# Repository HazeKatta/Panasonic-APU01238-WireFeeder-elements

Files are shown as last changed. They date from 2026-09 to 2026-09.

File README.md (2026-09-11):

# Panasonic Wire Feed Unit: `WGIII/APU01238`
***Available on*** [Onshape](https://cad.onshape.com/documents/fc67ad3c9c1f68b02d99dc8a/w/f257942ea42ffc9f7acd28aa/e/a838ed4791a7bb28b46b23de)
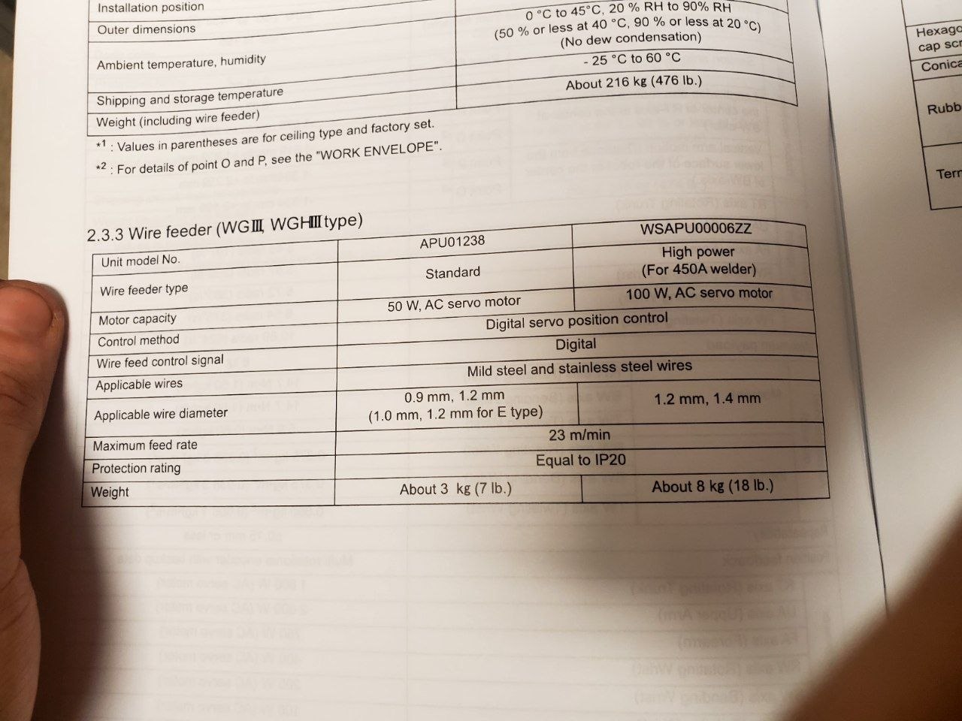
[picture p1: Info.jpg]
Real example


# What alternatives/spares does this repo provides

## Doors (2 variants):
Doors are not sold themselve you normally need to buy whole new `Wire Feeder` (or just not sold by Valk Welding B. V.)  
Price of those Doors was seen on EBay with 60$ price (used).
* Body: 2 variants
* Latch: 2 variants
* List of components like `seagers` and so on...
* Pin drawings  

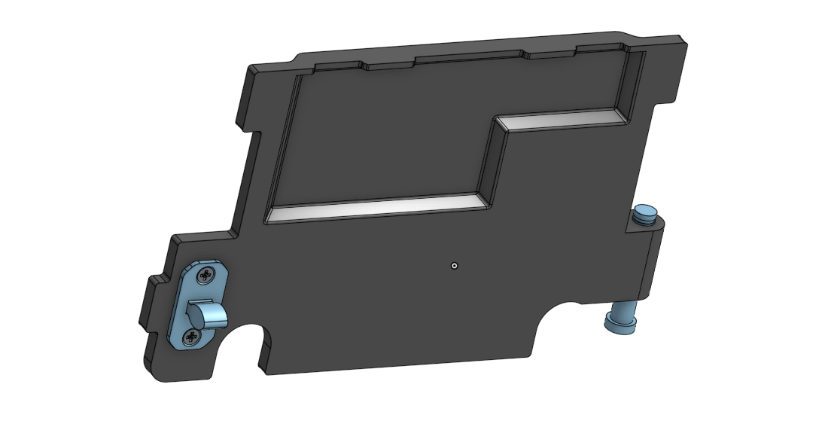
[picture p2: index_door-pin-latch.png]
Classic

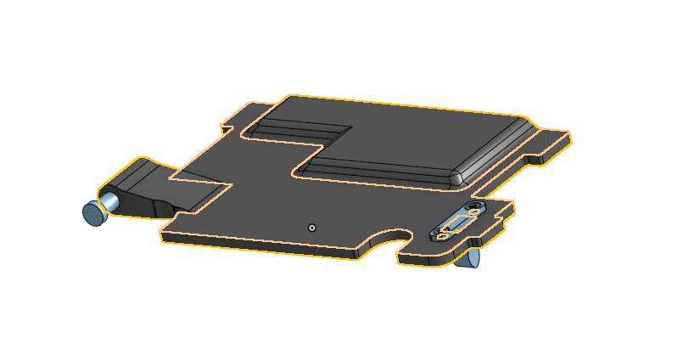
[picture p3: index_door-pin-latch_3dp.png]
More 3D printer friendly


## Mount:
* Metal bracket: classic & sheet metal alternative (2&4 mm sheets)  
* Insulator
* Metal L-profile seen below
* OFC: list of standard components

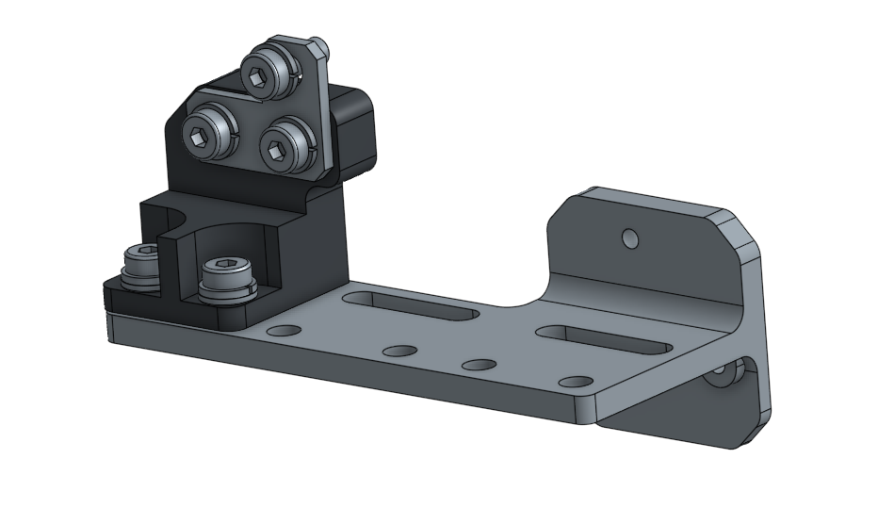
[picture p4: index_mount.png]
  

## Inside wire guide right between the rollers
* Brass block drawings
* Guide tube dimensions
* Used screws  

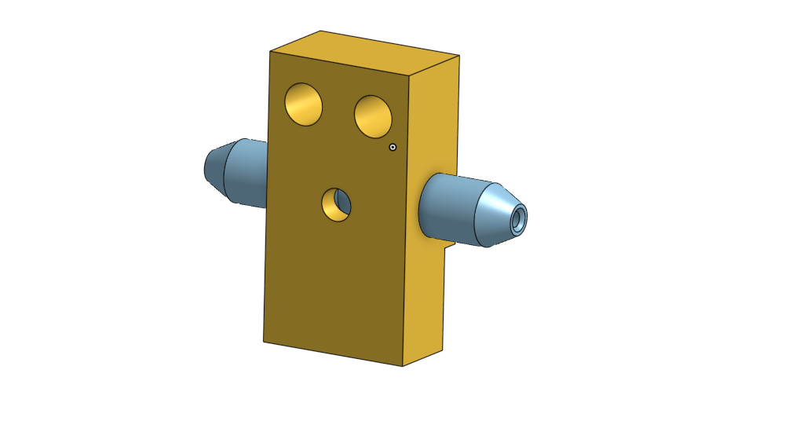
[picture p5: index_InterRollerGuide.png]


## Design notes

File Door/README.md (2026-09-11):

# Door
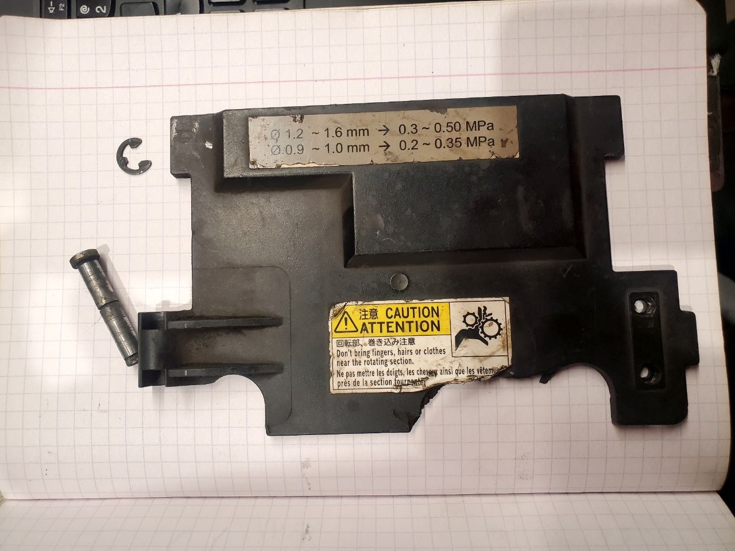
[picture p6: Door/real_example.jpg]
Real example

Consists of **one** element, but as you can see `it` also requires:
* [magic pin (click to go to it's section)](#door-pin) - can be made from soft material, even from plastic if needed
* magic Seager E-Clip:
  * outer diameter: 11mm
  * inner diameter: 5.20-5.50mm
  * thickness: 0.7mm (up 1.0mm)

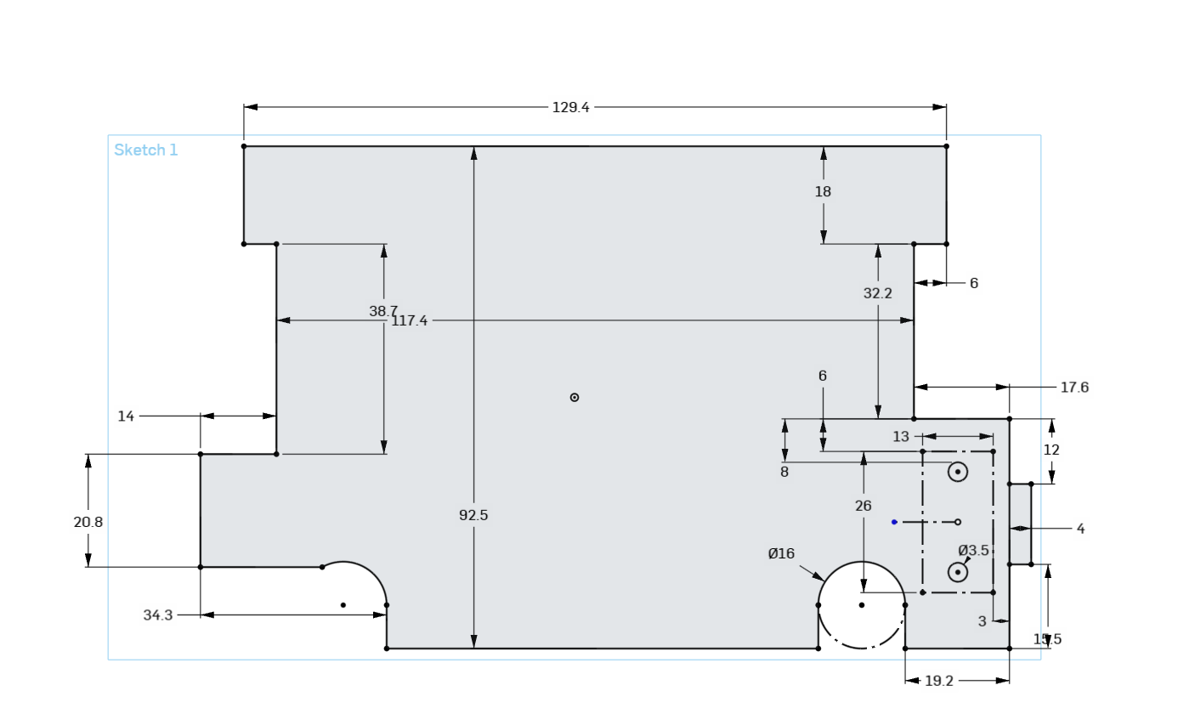
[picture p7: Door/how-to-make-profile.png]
how to recreate?

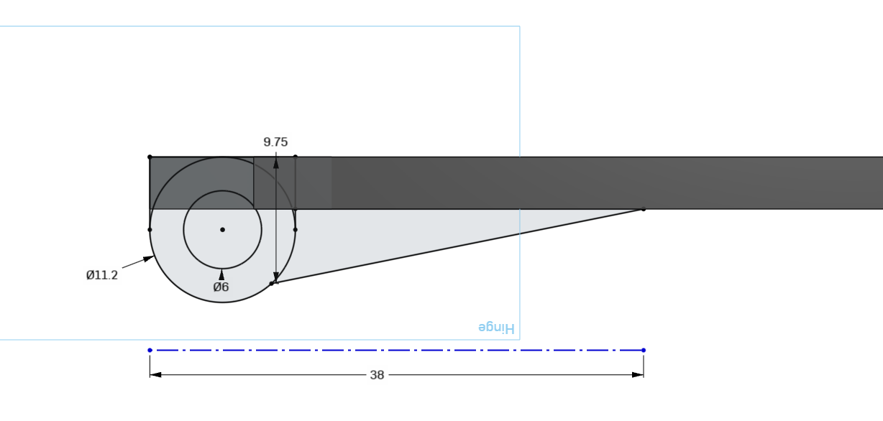
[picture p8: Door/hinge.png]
how to recreate hinge?

#### Plate is 3mm thick
### How does proposed alternative look like?
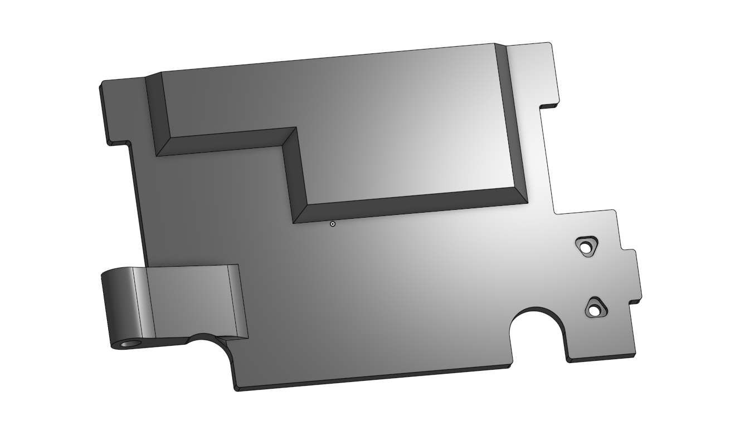
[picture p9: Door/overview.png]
3D printed alternative

As you can see cutouts for M2.5 nuts are triangular to cut accelerate/decelerate ops. for faster printing. Those nuts don't get fasten enough to maximize contact area.

#### 3D printing friendlier version
**Note that alternative versions are not cross-compatible!**
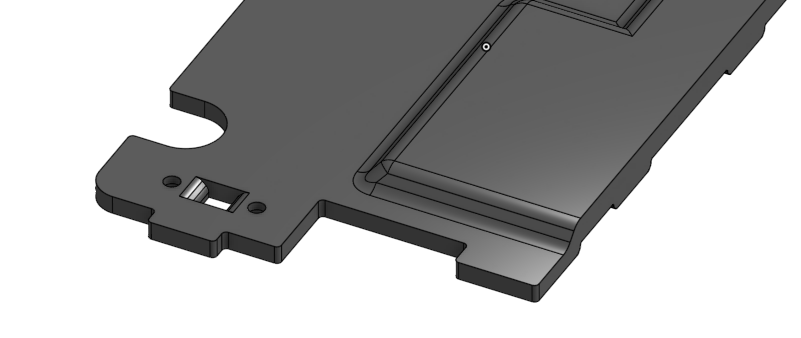
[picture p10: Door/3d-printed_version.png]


## Door pin
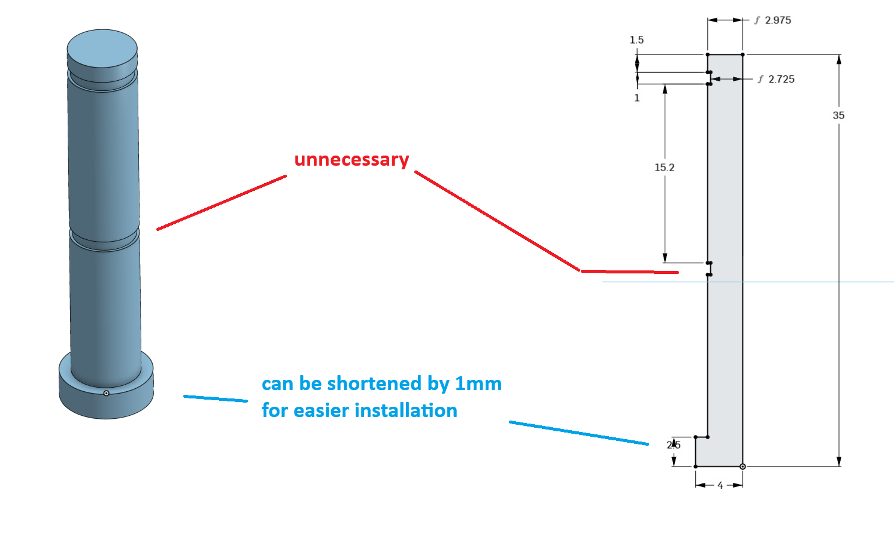
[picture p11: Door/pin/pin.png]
overview

Pin can be made from soft material on lathe or even plastic, but soft steel or aluminum is recommended.

## Door Latch
When printing using `FDM planar 3D printer`:  
* use 100% infill
* orient this on the side
* use support
* material: PP (chemical resistance) or PCTG - for better layer adhesion and UV resistance

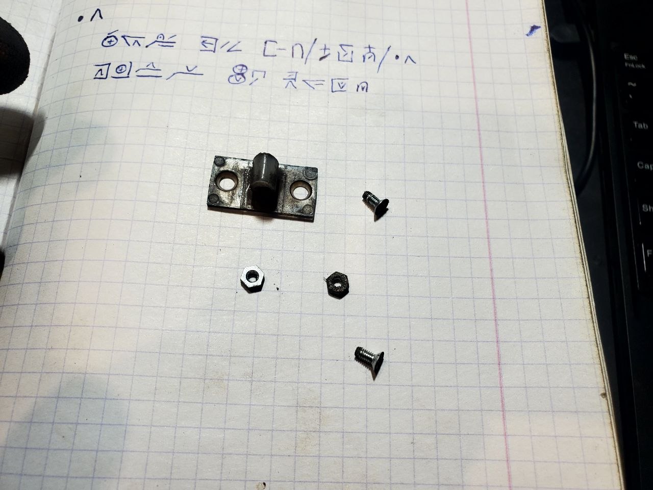
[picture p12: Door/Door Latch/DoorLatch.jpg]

### Parts:
1. 2x M2.5x5.6mm Phillips flat-head contersink machine screws
2. 2x M2.5 Nuts: Wrench 5mm
3. PP or PP-like body

### Anatomy
As you can see it's profile resembles B-Plug of which you may have printed a lot of, but this is thin be careful with it. And stick to a `6mm dimention` not `R5.47`.  
Circle/hole in center `(3mm one)` is not needed because the latch does not squish .
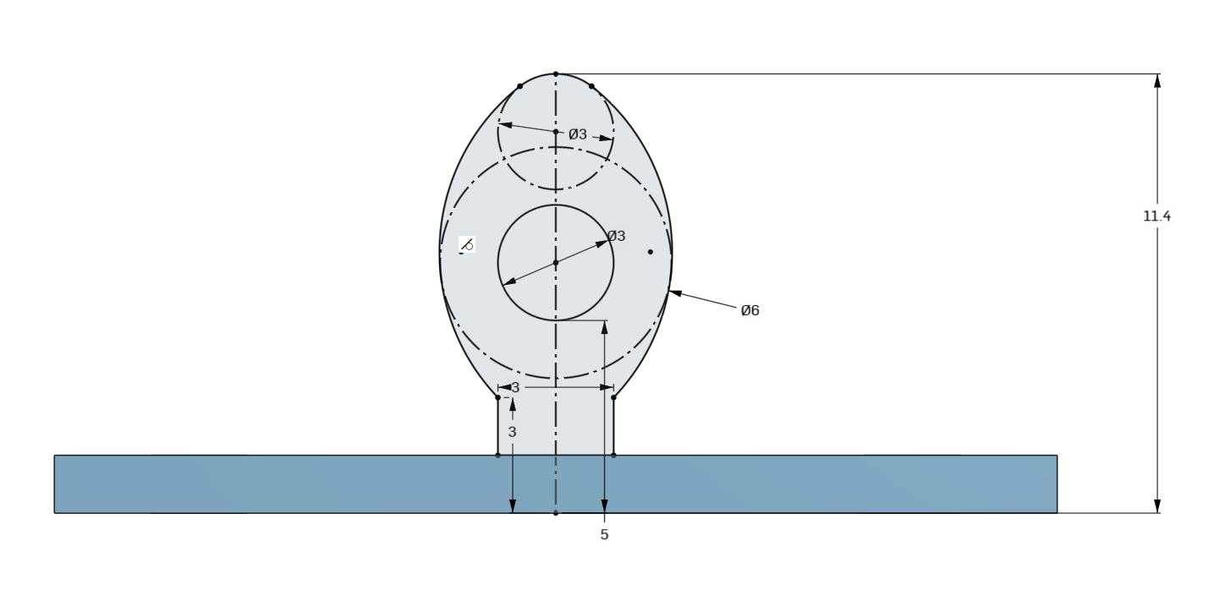
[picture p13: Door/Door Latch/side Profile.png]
How to recreate

Simple drawing
#### 3D printing friendlier version
**Note that alternative versions are not cross-compatible!**
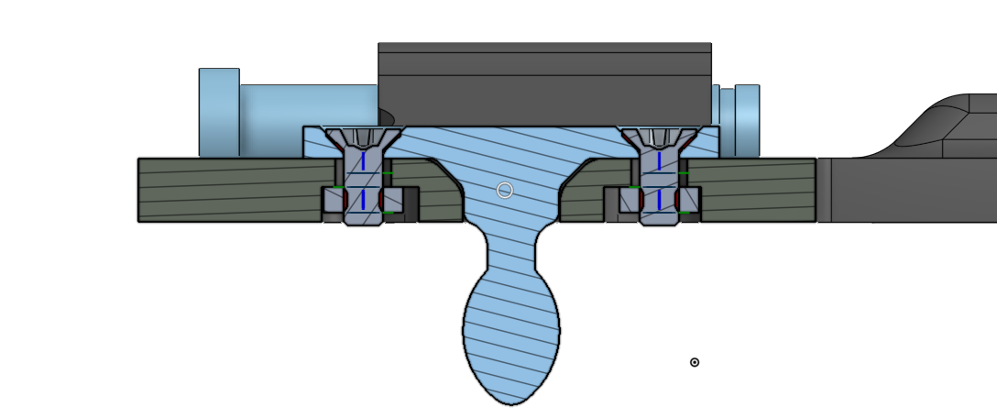
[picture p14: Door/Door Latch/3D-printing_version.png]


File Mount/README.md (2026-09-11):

# APU01238 mounting alternative parts:
**Custom Elements:**
* [Insulator](#insulator)
* [Metal Bracket](#bracket-unit-wg-afu01355-alternative)
* [Metal connector plate](#metal-connector-plate)  

**Standard Elements:**
* **5x** `DIN 912` M6x15:
    * **3x** thread >11.5mm
    * **2x** thread >10mm
* **2x** M6 nuts
* **2x** `ANY` plain 6mm washers with OD < 14.9mm
* **2x** 6mm `DIN 7980` spring washers
* **3x** 6mm `DIN 6798A` "spring" washers

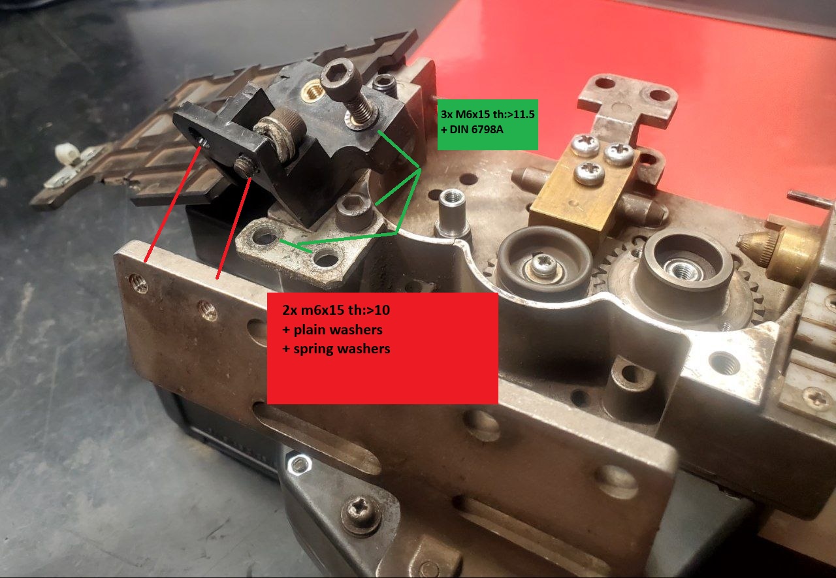
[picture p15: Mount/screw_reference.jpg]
Reference


# Insulator
Original has threaded inserts but M6 nuts are more popular ammong commoners.
3D printer version

# Bracket unit WG (AFU01355) alternative
Original is `casted` and then `machined`, so alternative is proposed.
You can try recreating this part using Lost-PLA method (like lose wax but w/ 3D printing).
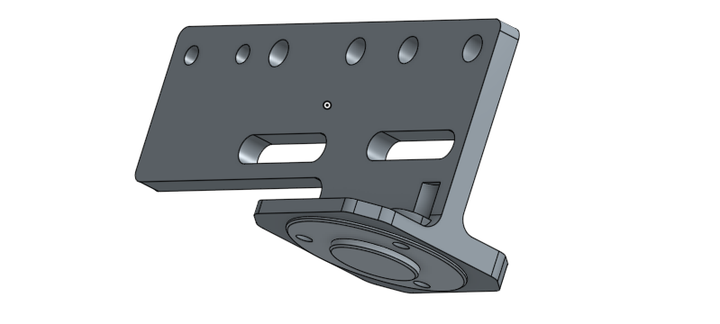
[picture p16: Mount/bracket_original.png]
Original
  
## Proposed alternative consists of 5 sheetmetal parts from popular `4` & `2` [mm] thick sheets welded together.
DXF's have already tolerances (0.2-0.3mm).
### Assembly:
First align and weld those to parts together filling additional holes and welding edges. If neccesary grind flat.  
**DON'T weld bottom** `TABS`**.**  
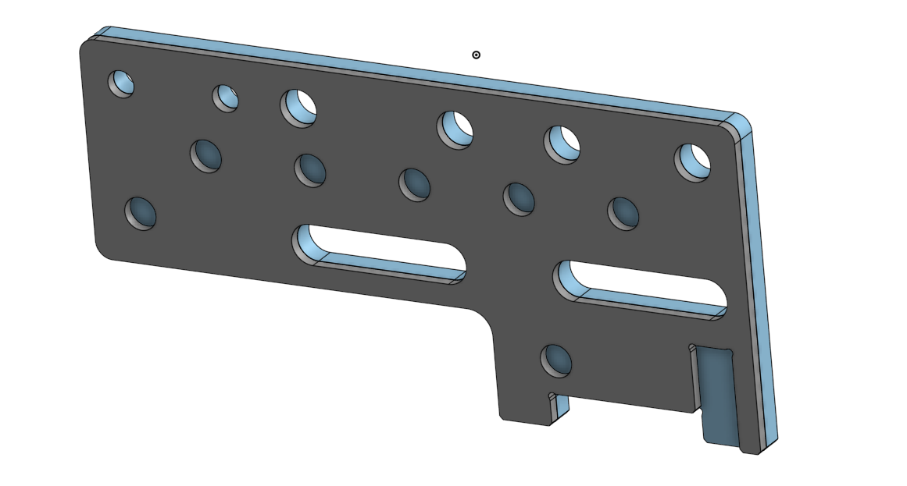
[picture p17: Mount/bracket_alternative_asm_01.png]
Main
  

Align and weld edges.  
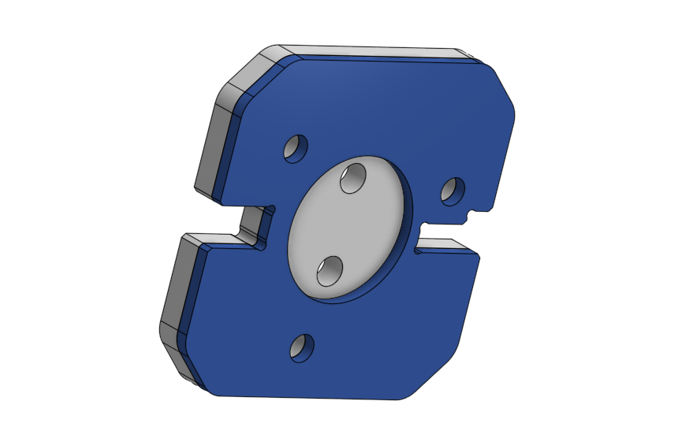
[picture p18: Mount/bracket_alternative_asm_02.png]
Base
  

Align centering circle and weld together, do a chamfer with some kind of drill if necessary. Original thought was to weld 3.2mm TIG wire but not everyone has 3.2mm TIG wire.
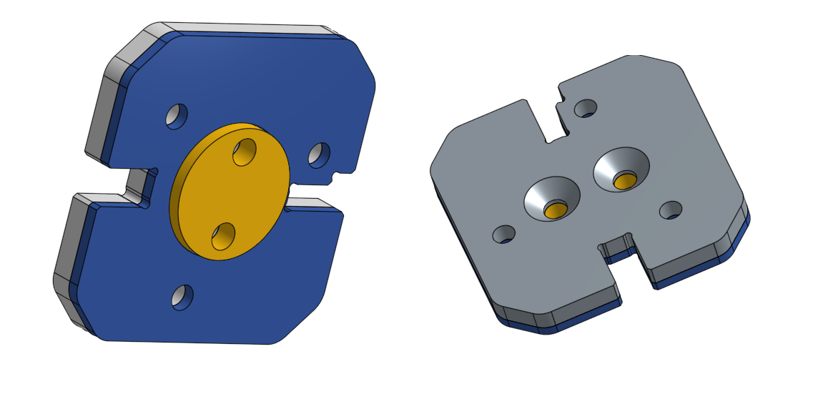
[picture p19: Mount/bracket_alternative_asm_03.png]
  

Finnish by tapping some holes & welding it together and grinding.
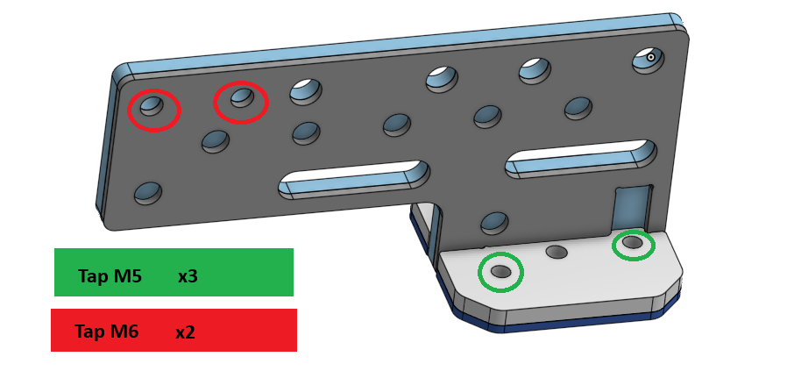
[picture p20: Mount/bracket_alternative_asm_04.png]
  

# Metal connector plate
Recommended to add fillets for laser cuting.
Reference

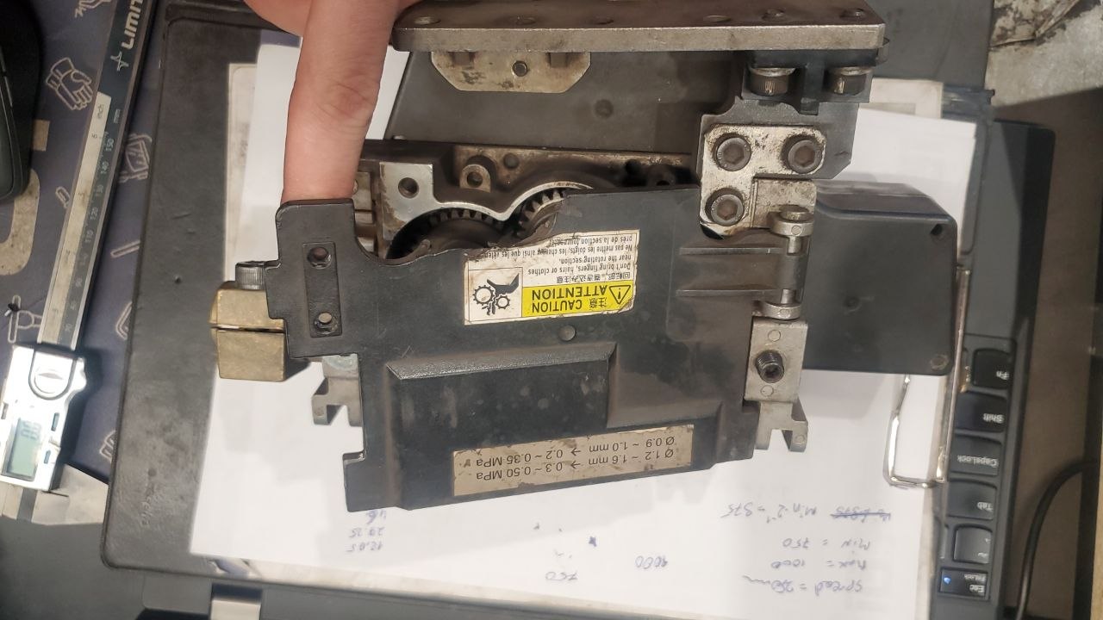
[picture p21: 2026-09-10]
Door/on_wire_feeder.jpg

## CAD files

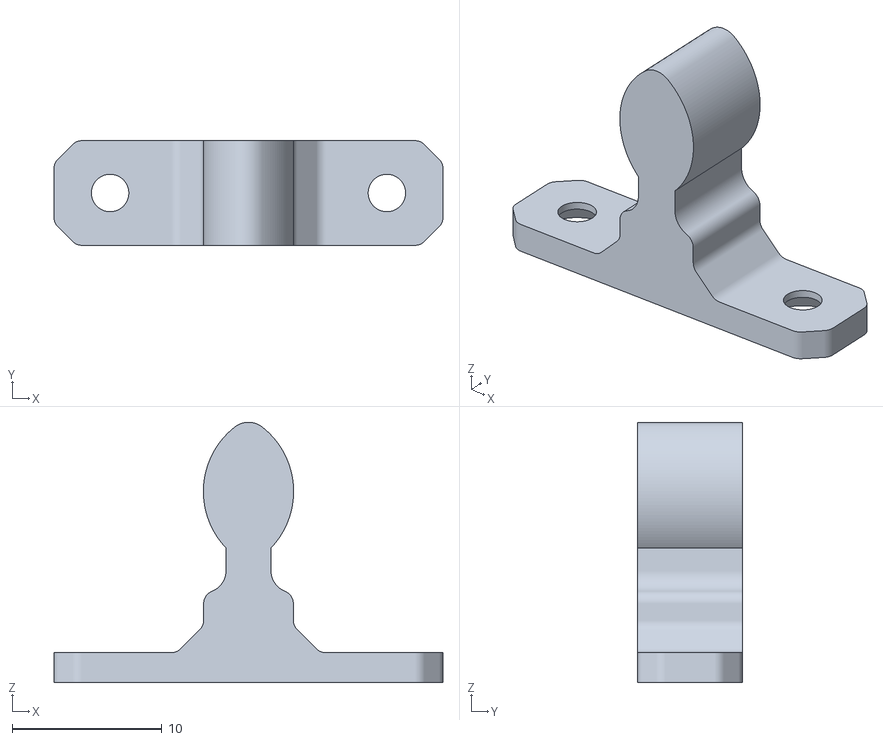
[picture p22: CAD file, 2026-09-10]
Door/Door Latch/Latch_3Dp.stl
26.0 x 7.00 x 17.4

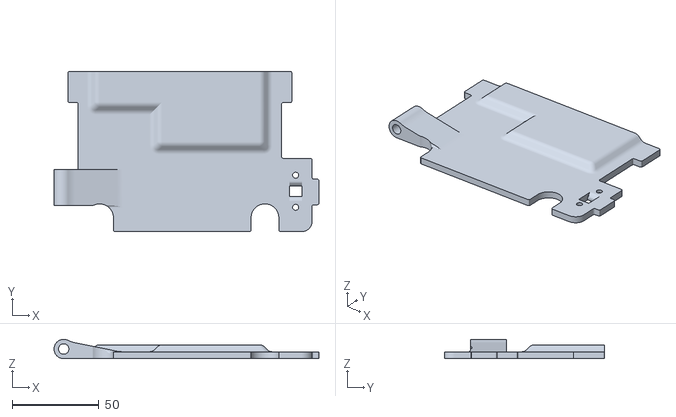
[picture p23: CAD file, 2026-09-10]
Door/Door_better_for_3D-printing.stl
153.0 x 92.5 x 11.2

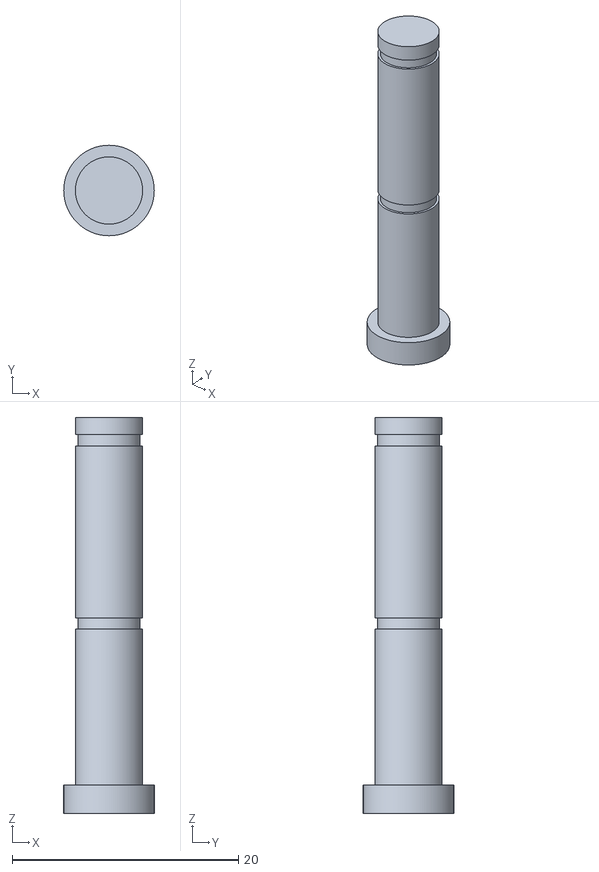
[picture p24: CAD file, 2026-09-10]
Door/pin/Pin.stl
8.00 x 8.00 x 35.0

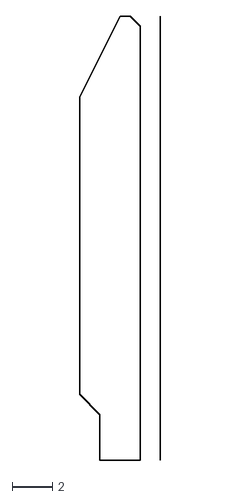
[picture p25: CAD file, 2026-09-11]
InterRollerGuide/GuideTube_sketch.dxf
4.00 x 22.0

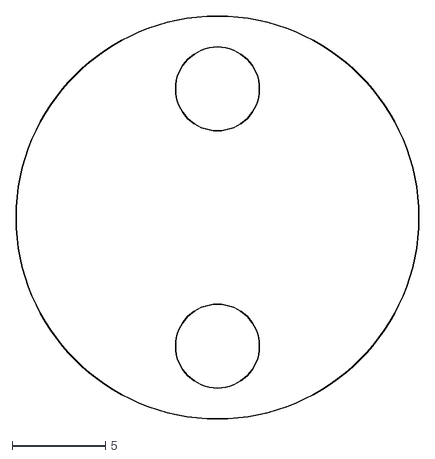
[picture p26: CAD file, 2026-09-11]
Mount/Z_Bracket_laser-cut-welded - 4mm_center.dxf
21.6 x 21.6

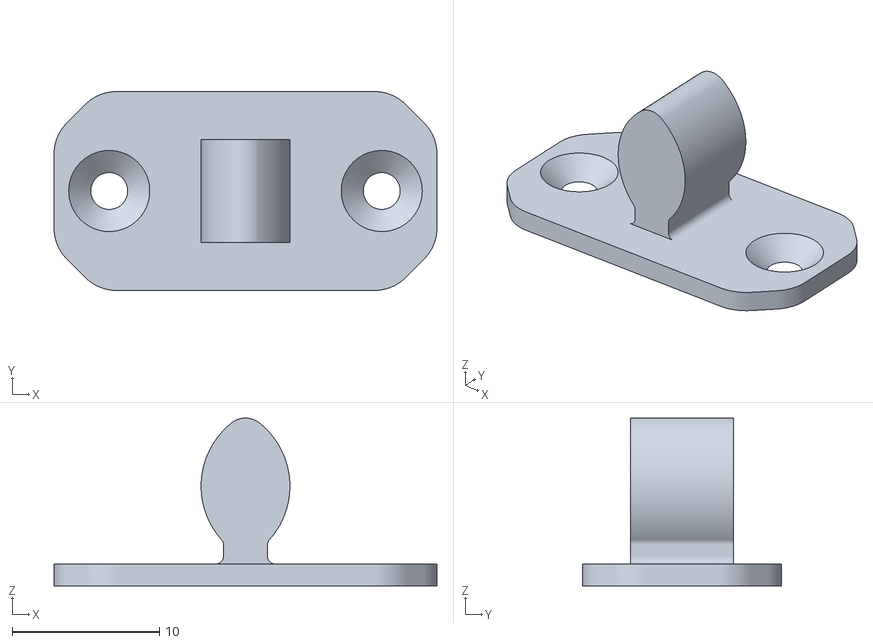
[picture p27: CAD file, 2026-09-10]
Door/Door Latch/DoorLatch.stl
26.0 x 13.5 x 11.4

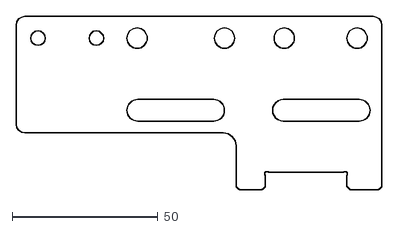
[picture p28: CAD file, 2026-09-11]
Mount/Z_Bracket_laser-cut-welded - 4mm_sail.dxf
125.5 x 59.5

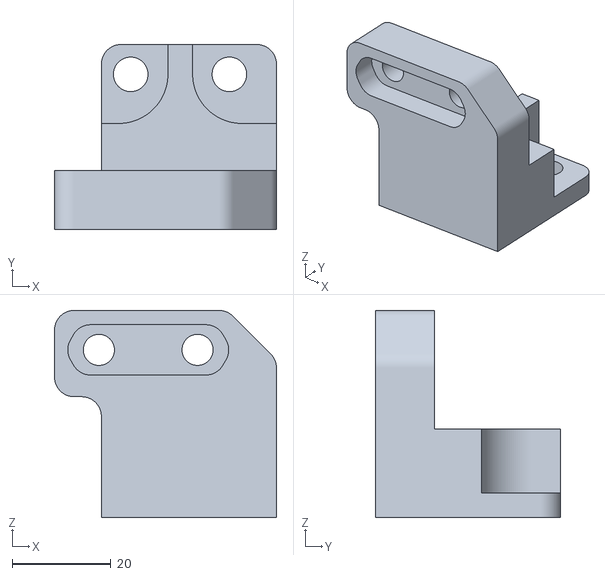
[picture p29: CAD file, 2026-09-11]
Mount/insulating_WF-mount.stl
45.0 x 37.5 x 42.0

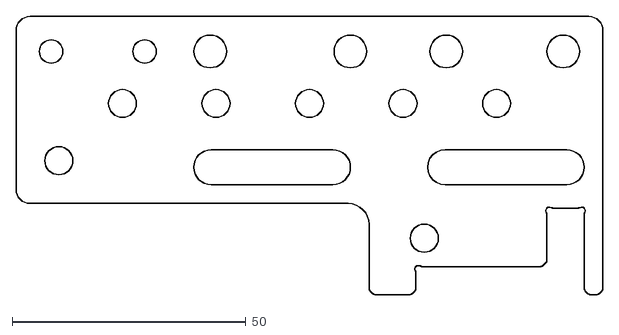
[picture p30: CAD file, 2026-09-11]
Mount/Z_Bracket_laser-cut-welded - 2mm_sail.dxf
125.5 x 59.5

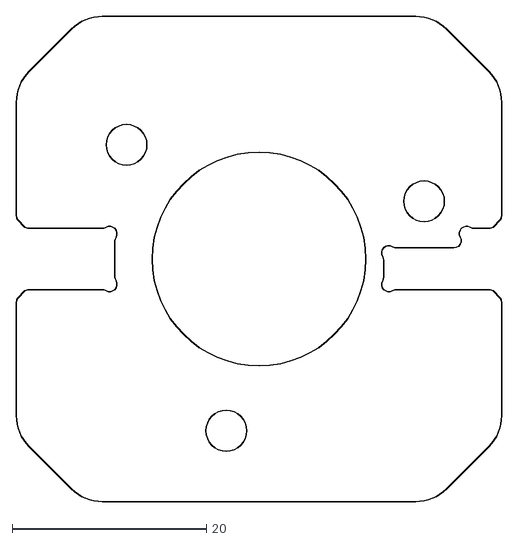
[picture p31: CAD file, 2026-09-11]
Mount/Z_Bracket_laser-cut-welded - 2mm_base.dxf
50.0 x 50.0

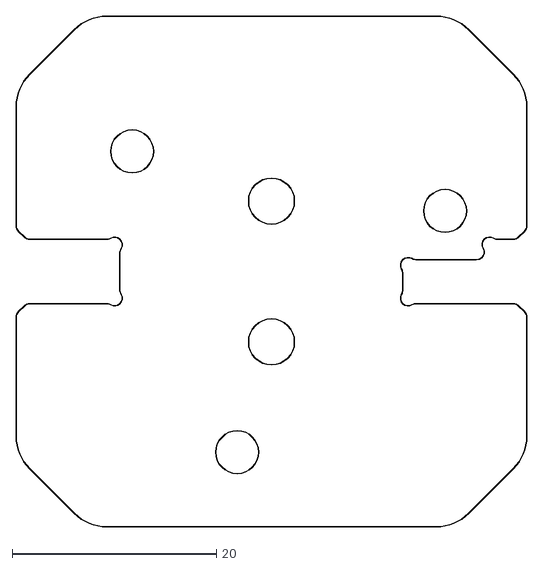
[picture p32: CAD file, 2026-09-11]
Mount/Z_Bracket_laser-cut-welded - 4mm_base.dxf
50.0 x 50.0

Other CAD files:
Door/Door.stl

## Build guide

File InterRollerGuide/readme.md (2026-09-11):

# Wire Guide in between rollers
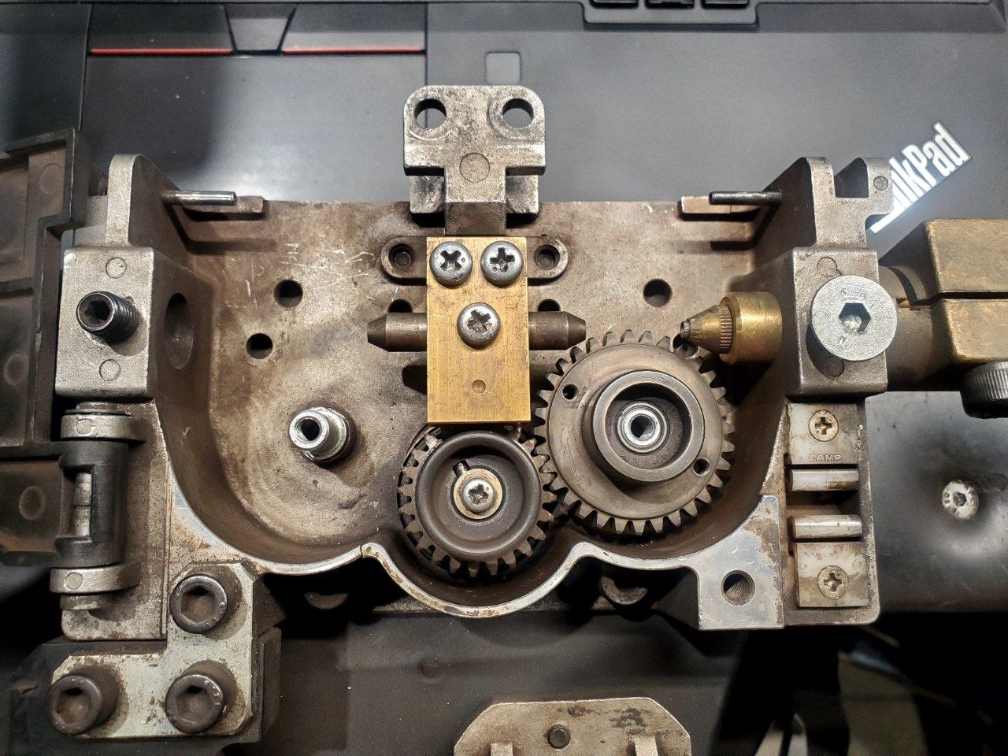
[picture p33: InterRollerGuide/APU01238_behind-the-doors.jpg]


# Parts:
* 1x `DIN 7985H` M5x4.5 Phillips screw
* 2x `DIN 7985H` M5x20 Phillips screw
* Brass Block
* Guide Tube

# Brass Block
Simple drawing

# Guide Tube
Needs to be revolved and mirrored.  
Can be made with lathe from material harder than wire or tool steel (eg. C45)
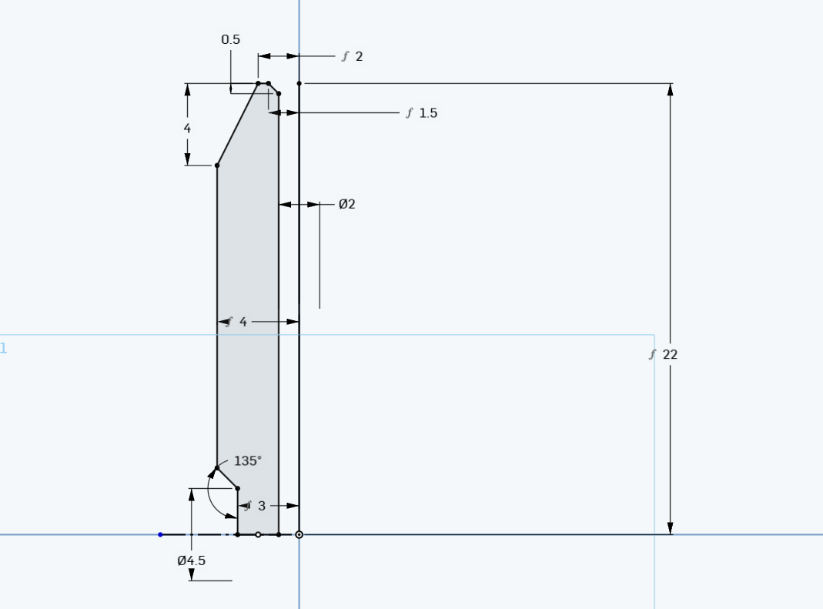
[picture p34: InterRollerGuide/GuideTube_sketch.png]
You would have to revolve and mirror


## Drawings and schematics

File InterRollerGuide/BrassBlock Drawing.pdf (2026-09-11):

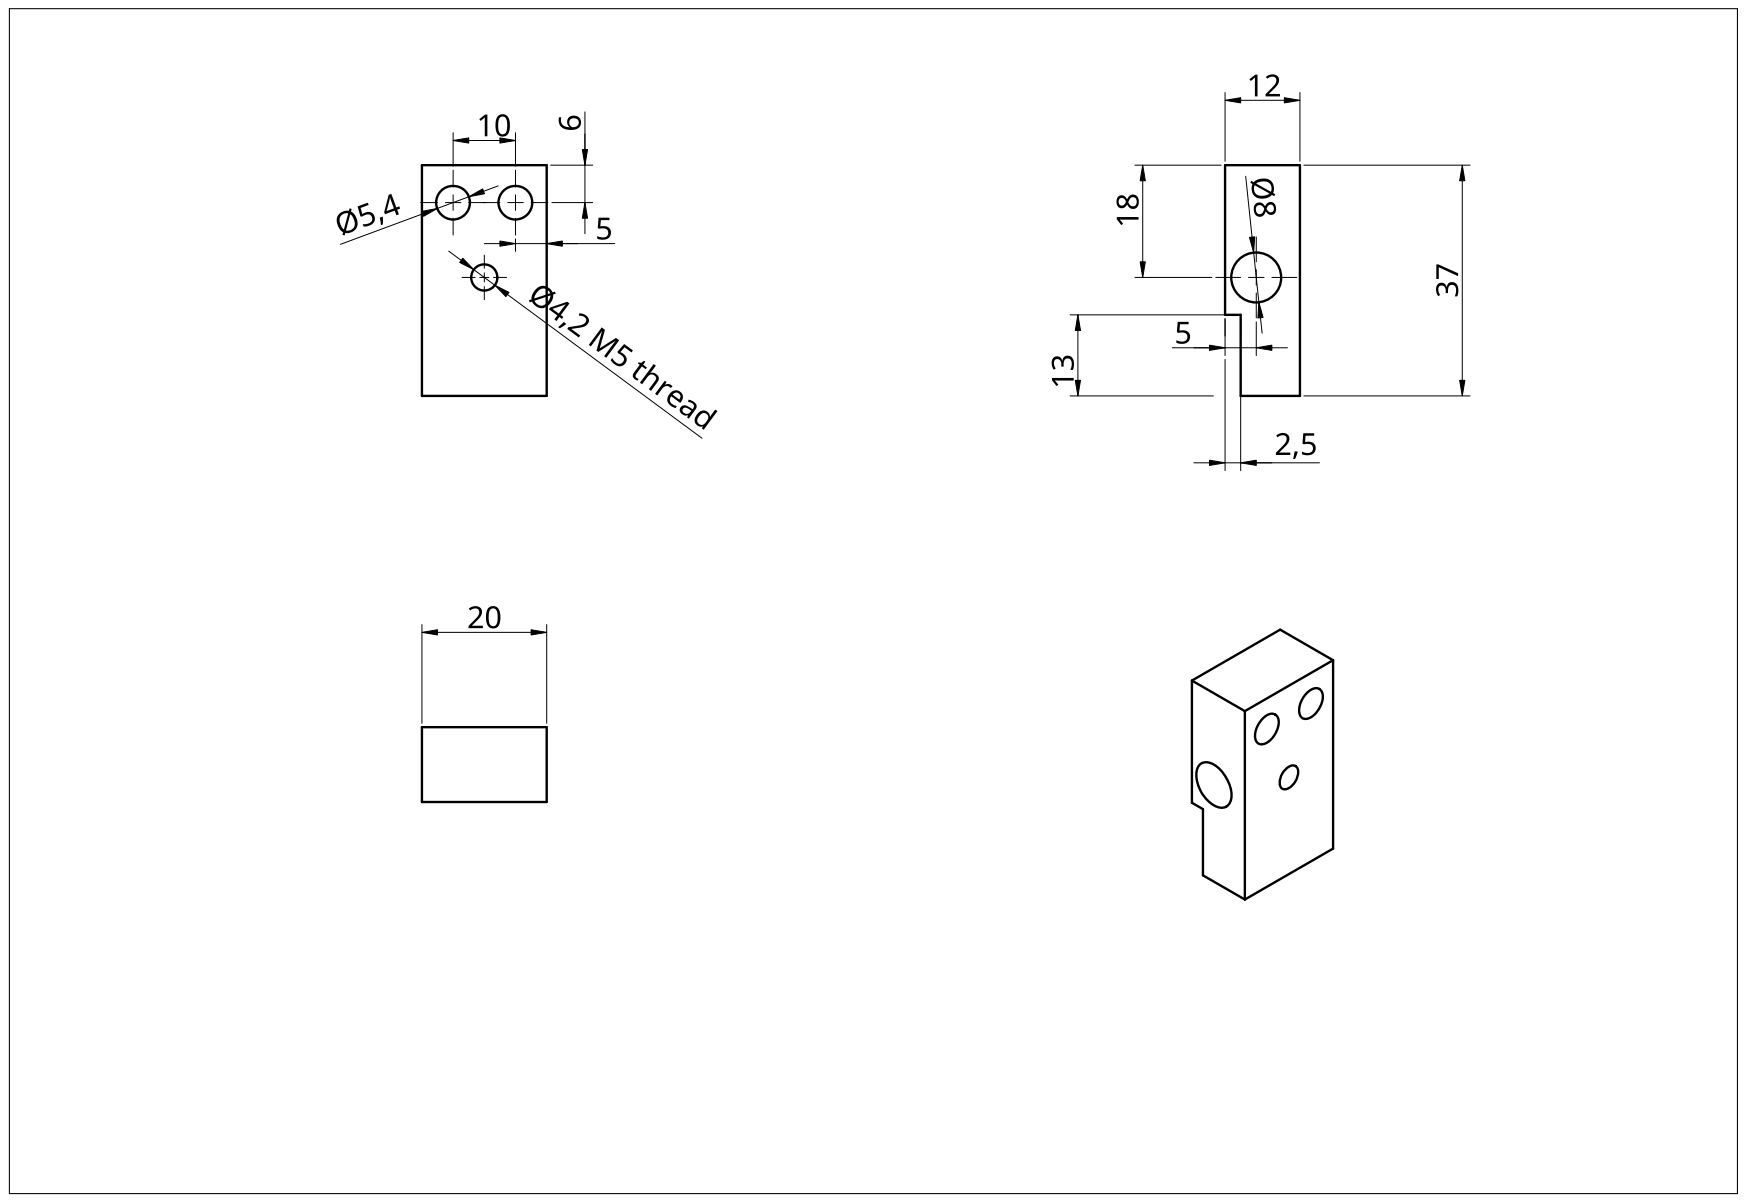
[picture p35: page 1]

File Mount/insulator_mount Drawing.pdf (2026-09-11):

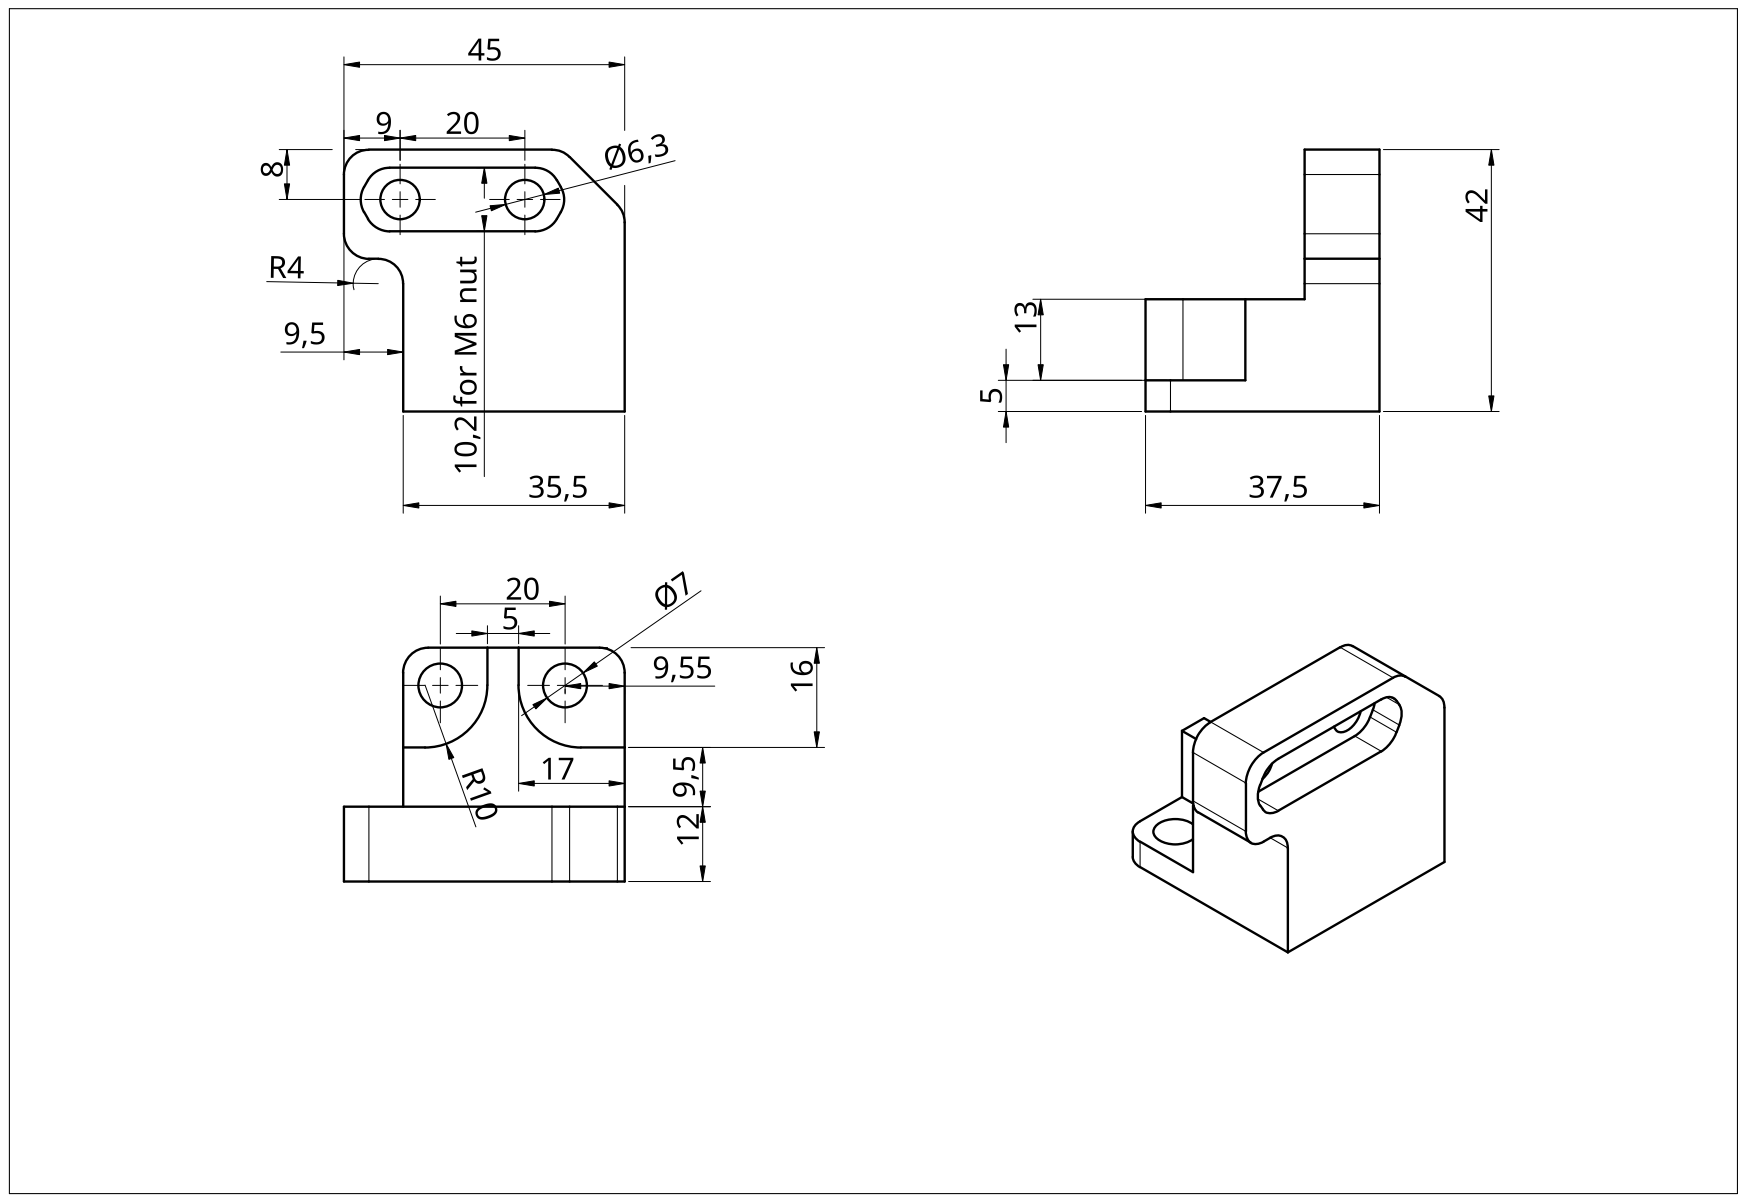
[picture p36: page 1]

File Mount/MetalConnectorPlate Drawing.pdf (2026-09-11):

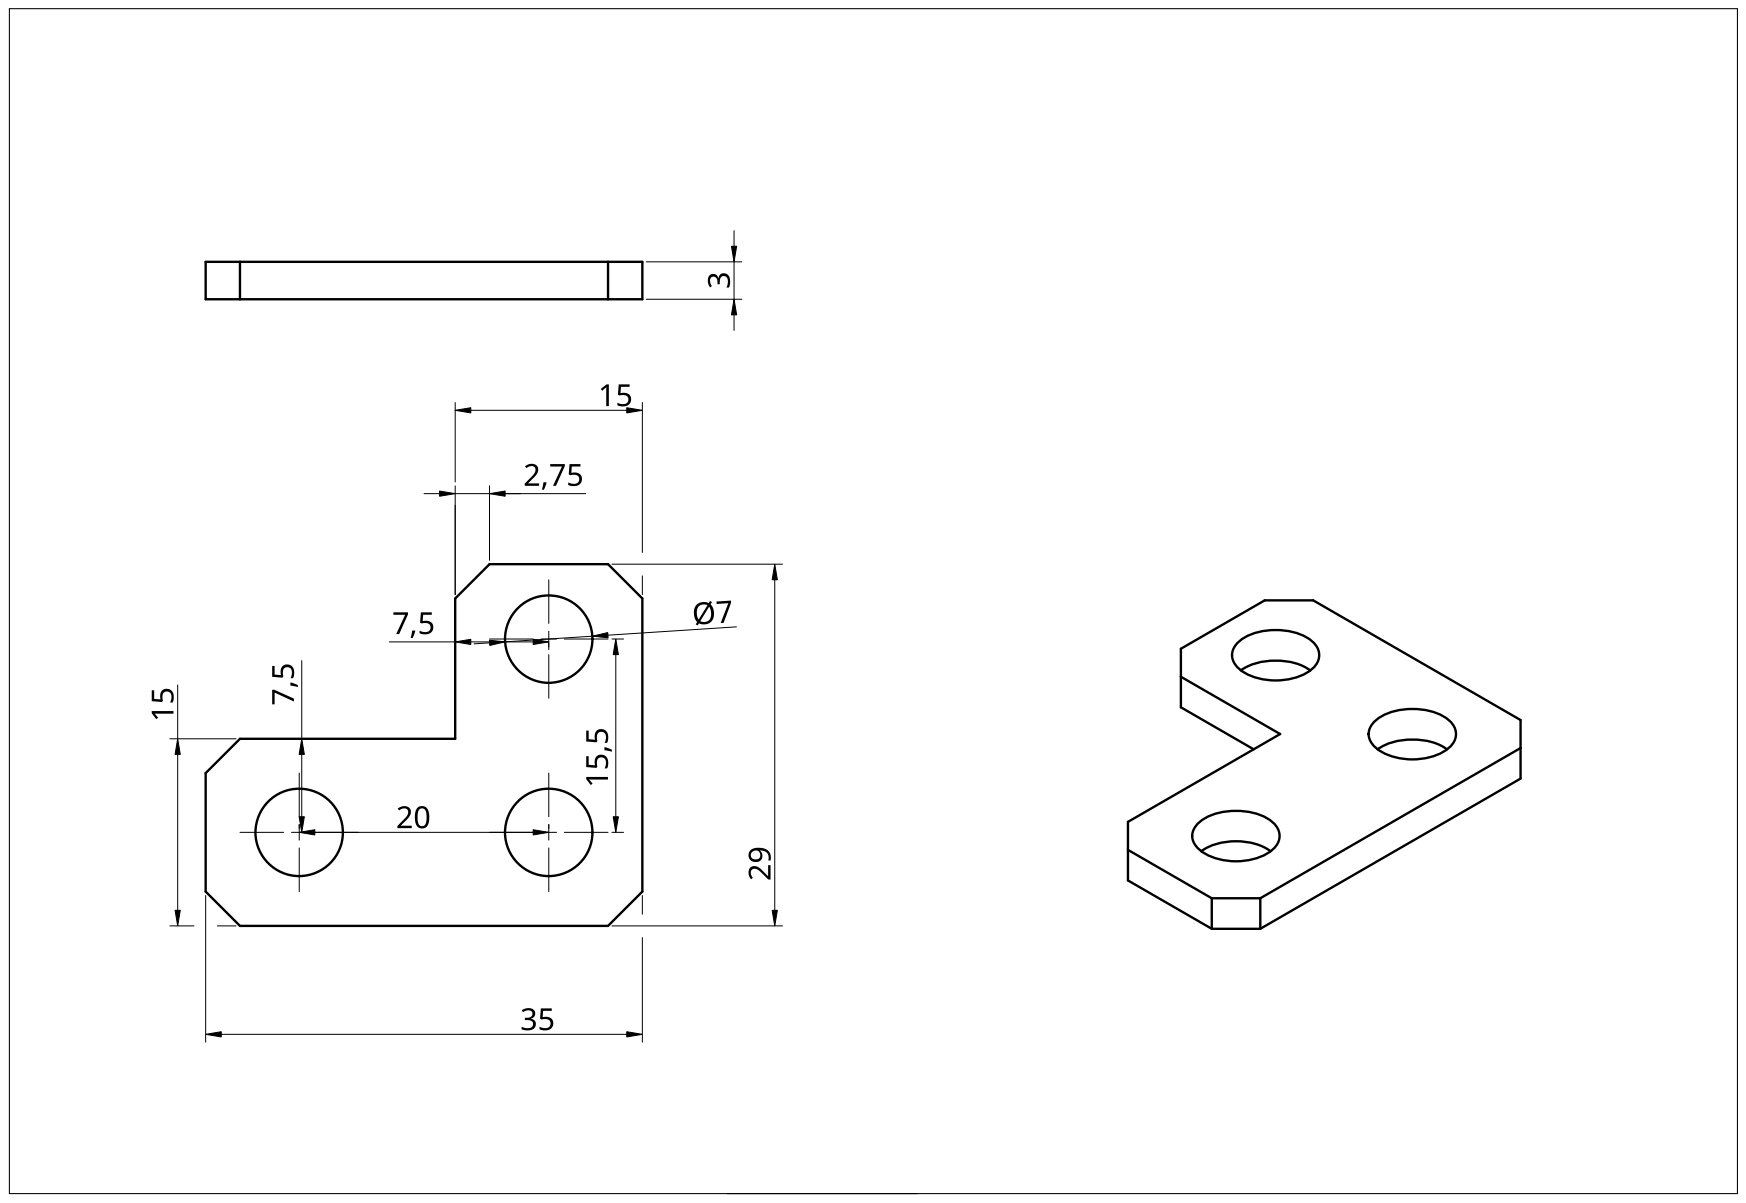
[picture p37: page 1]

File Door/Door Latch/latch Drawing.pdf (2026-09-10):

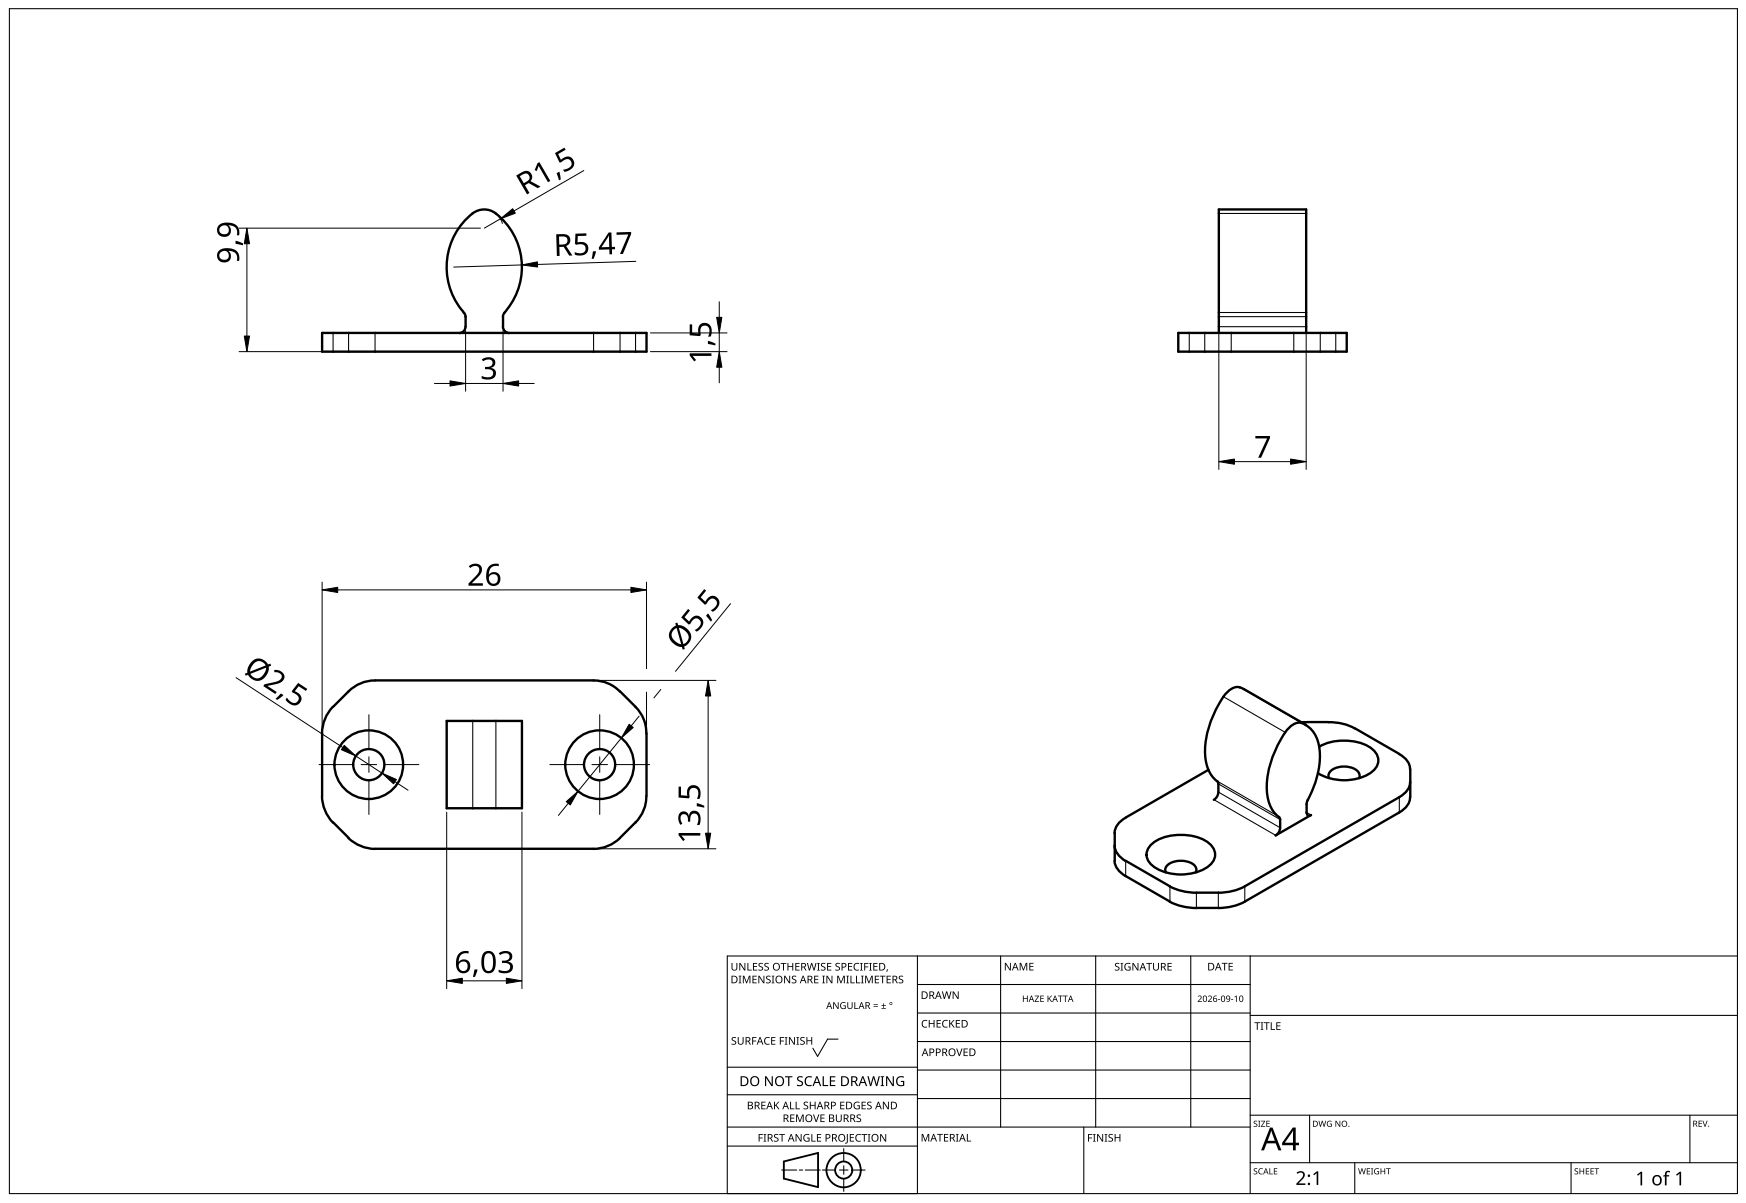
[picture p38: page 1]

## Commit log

2026-09-10 First content commit
    [Door.stl, DoorLatch.stl, Door_better_for_3D-printing.stl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]
2026-09-10 Added tolerance
    Added tolerance in hole for 3D printing friendly version.
    [Door_better_for_3D-printing.stl]
2026-09-10 Rename Latch_3Dp.stl to Latch_3D-printable.stl
    Name change
    [Latch_3D-printable.stl]
2026-09-10 Update README.md
    Specified thickness of door plate
2026-09-11 Overhaul
    Cleaned and better documented
    + some new elements like: mounting and inner wire guide elements.
    [DoorLatch.stl, GuideTube_sketch.dxf, Latch_3Dp.stl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]
2026-09-11 Delete Door Latch directory
    move into 'Door'
    [DoorLatch.stl, Latch_3D-printable.stl]
2026-09-11 Delete pin directory
    moved into 'Door'
    [Pin.stl]
